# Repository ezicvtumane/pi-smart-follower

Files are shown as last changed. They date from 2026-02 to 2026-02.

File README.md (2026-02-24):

<p align="center">
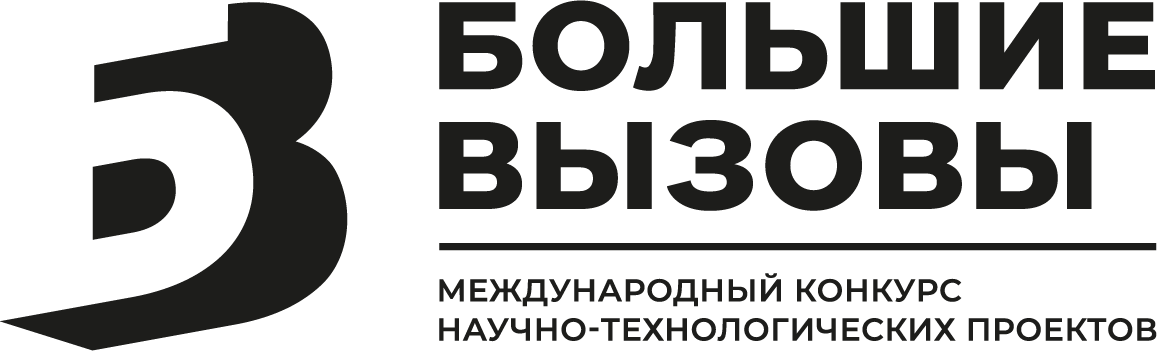
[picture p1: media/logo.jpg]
  
</p>

# Alice's Bot: Autonomous Smart Follower 🤖

Мобильный робот на базе Raspberry Pi 4 с элементами искусственного интеллекта и удаленным веб-управлением. 
Проект разработан в рамках Международного конкурса научно-технологических проектов **«Большие вызовы»** (направления: «Транспортно-логистические системы, морские, авиационные и беспилотные технологии» / «Большие данные, искусственный интеллект, автоматизированные системы и информационная безопасность»).

Робот может управляться вручную через мобильный веб-интерфейс (с трансляцией видео от первого лица), а также умеет автономно ездить за оператором или объектом, ориентируясь по визуальным ArUco-маркерам.

<p align="center">
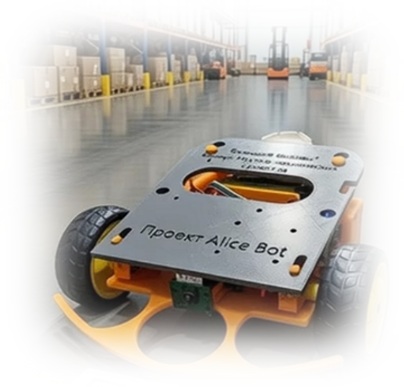
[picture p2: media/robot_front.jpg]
  
</p>

---

## 🧠 Как это работает (Архитектура и Алгоритмы)

Главная фишка программной части (Python 3) в том, что она работает в два независимых потока (через библиотеку `threading`). Один поток постоянно анализирует зрение и рулит моторами, а второй — держит веб-сервер Flask и отдает видео без тормозов.

1. **Компьютерное зрение (OpenCV + Picamera2):** Скрипт захватывает кадр в высоком разрешении для FPV, но для модуля машинного зрения программно ужимает его и переводит в ЧБ. Алгоритм ищет ArUco-маркер (словарь `DICT_4X4_50`) и вычисляет его центр.
2. **Автопилот (П-регулятор):** Если робот видит маркер, программа считает, насколько его центр отклонился от центра камеры. Это отклонение умножается на коэффициент, и разница подается на колеса. В итоге робот плавно подруливает без рывков.
3. **Система безопасности «Автостоп»:** Чтобы робот не врезался в ноги (или в кота), алгоритм непрерывно анализирует ширину маркера. Как только она превышает 180 пикселей (~30 см до объекта), моторы экстренно останавливаются.
4. **Zero-ping интерфейс:** В мобильном браузере обычные клики по кнопкам управления имеют огромную задержку. Я переписала HTML-шаблон Flask, заменив стандартные клики на прямую обработку касаний экрана (`ontouchstart` / `ontouchend`). В итоге отклик стал мгновенным, как на аппаратном джойстике.

---

## 🛠 Железо (Hardware)

* **Мозг:** Одноплатный микрокомпьютер Raspberry Pi 4.
* **Глаза:** Компактный модуль камеры OV5647 (подключен по CSI).
* **Шасси:** Спроектировано мной и напечатано на 3D-принтере (STL-файлы лежат в папке `3d_models`). В качестве пассивного третьего колеса интегрирован гладкий шар от роликового дезодоранта.
* **Драйвер моторов:** Промышленный модуль L298N с радиатором. *(Изначально я использовала компактный L9110S, но он сгорел во время тестов от высоких пусковых токов ТТ-моторов, поэтому схему пришлось переделать под более мощный ключ).*
* **Питание (Два контура):** Сборка 2S Li-ion 18650 (7.4В) питает напрямую драйвер моторов. Для питания чувствительной логики Raspberry Pi используется понижающий импульсный DC-DC преобразователь (выдает стабильные 5В напрямую на пины GPIO 4 и 6).

---

## 🚀 Установка и запуск

1. Склонируйте репозиторий на вашу Raspberry Pi:

```bash
git clone https://github.com/ezicvtumane/pi-smart-follower.git
cd pi-smart-follower
  ```
2. Установите зависимости (камера Picamera2 должна быть включена в настройках ОС):

  ```bash
  pip install -r requirements.txt
  ```
4. Запустите основной скрипт:
  ```bash
  python3 main.py
  ````
5. Откройте интерфейс управления в браузере смартфона или ПК (устройства должны быть в одной Wi-Fi сети):
  ```
  http://<IP_АДРЕС_RASPBERRY>:5000
  ```
---

## ⚙️ Автозагрузка при включении (через systemd)

Чтобы робот был полностью автономным и не требовал подключения по SSH для запуска кода, настроена системная служба `systemd`. Она автоматически поднимает скрипт при включении питания, ожидая подключения Raspberry Pi к Wi-Fi сети (чтобы сервер Flask не упал с ошибкой сети).

1. Создайте файл службы:
```bash
    sudo nano /etc/systemd/system/alicebot.service
```
2. Скопируйте в него содержимое файла `alicebot.service` из этого репозитория.

3. Включите автозагрузку командами:
```bash
    sudo systemctl daemon-reload
    sudo systemctl enable alicebot.service
    sudo systemctl start alicebot.service
```
---

## 🔮 Перспективы развития (Roadmap)

В будущем планируется масштабный апгрейд робота, который переведет его из класса прототипов в полноценную платформу:
* **Внедрение нейросетей:** Переход на Raspberry Pi 5 + AI Kit. Использование легковесных сверточных нейросетей (например, YOLOv8) для детекции людей и управления жестами без бумажных маркеров.
* **Интеграция в Умный дом (IoT):** Подключение робота к серверу Home Assistant по протоколу MQTT для создания «роевого интеллекта» (swarm robotics) и диспетчеризации.
* **Безопасность и автономность:** Установка модуля BMS для аккумуляторов и ультразвуковых сонаров для полностью безопасного перемещения и автовозврата на зарядную станцию.

---

## 🎥 Демонстрация работы

Видео полевых испытаний алгоритмов (езда за меткой, автостоп, интерфейс):
* 📹 [Тест мобильного управления, следования за меткой и автостопа](https://disk.yandex.ru/i/8JQ_mCUT42CxUg)
* 📹 [Тест следования по ArUco маркеру](https://disk.yandex.ru/i/dgs2dP-XnfjGSw)
* 📹 [Тест FPV и следование за котом Серго](https://disk.yandex.ru/i/KrElrjvzCOmklQ)

---
**📝 Автор:** Ковалева Алиса, ученица 9-го класса ГБОУ СОШ №282 г. Санкт-Петербурга (2026 г.). Проект выполнен в рамках инженерно-исследовательской работы.

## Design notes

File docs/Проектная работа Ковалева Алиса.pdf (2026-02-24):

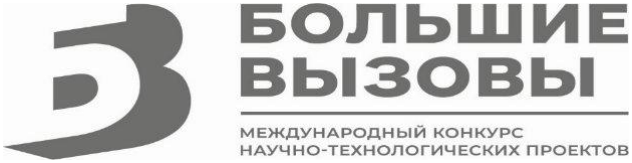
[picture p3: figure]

Направление: «Транспортно-логистические системы, морские, авиационные и беспилотные технологии», «Большие данные, искусственный интеллект, автоматизированные системы и информационная безопасность»

ПРОЕКТНАЯ РАБОТА

Тема: «Разработка мобильного робота с элементами искусственного интеллекта и

удаленным веб-управлением»

Выполнила: ученица 9 «А» класса

ГБОУ СОШ №282 г. Санкт-Петербурга

Ковалева Алиса Ивановна

Санкт-Петербург

2026 г.

### 1. ВВЕДЕНИЕ

Актуальность проекта Развитие современной робототехники неразрывно связано

с компьютерным зрением. Большинство существующих роботизированных платформ

перемещаются «вслепую», опираясь на таймеры или базовые датчики расстояния

(ультразвуковые или лидары). В отличие от них, системы визуальной навигации

позволяют роботу не просто избегать механических столкновений, но и узнавать объекты

в пространстве, анализировать их положение и самостоятельно принимать решения о

корректировке маршрута.

Проблематика Одной из главных проблем современной складской логистики и

автоматизации закрытых помещений (например, больниц или "чистых" зон) является

недоступность спутникового сигнала GPS. Для ориентации тяжелых транспортных

платформ внутри зданий нередко применяются дорогостоящие лазерные дальномеры

(лидары). Использование дешевых оптических камер в связке с бумажными ArUco-

маркерами решает эту проблему, позволяя создать экономичную и высокоточную систему

навигации.

Цель проекта Самостоятельно создание автономного мобильного робота, из

имеющихся в продаже недорогих компонентов, способного не только управляться

дистанционно через веб-интерфейс, но и самостоятельно следовать за целью по заданным

визуальным меткам.

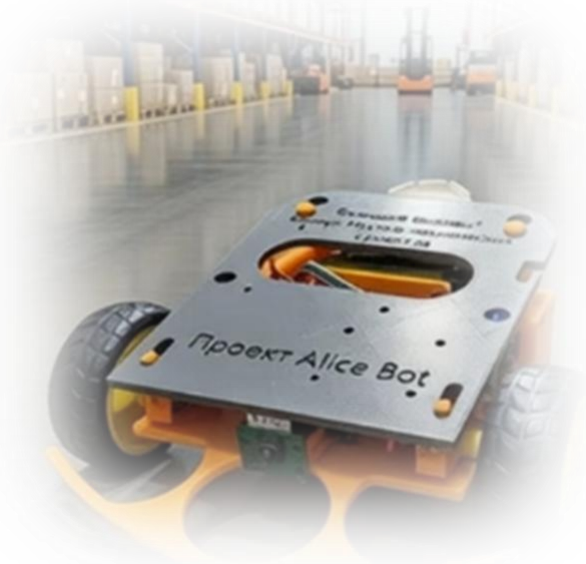
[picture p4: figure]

Задачи проекта:

1. Спроектировать и собрать работающий аппаратный прототип устройства

(разработка шасси, подбор компонентов, реализация подсистемы питания).

2. Реализовать алгоритмы компьютерного зрения для распознавания ArUco-

маркеров и настроить захват видеопотока в операционной системе Linux.

3. Разработать и развернуть кроссплатформенный веб-интерфейс для

обеспечения удобной системы удаленного контроля и FPV-управления.

Объект исследования: Автономные мобильные роботизированные платформы и

система компьютерного зрения.

Предмет исследования: Алгоритмы визуальной навигации (компьютерного

зрения) и системы дистанционного управления на базе веб-технологий.

Практическая значимость: Реализованный в проекте программный код и

аппаратная архитектура являются готовой масштабируемой базой (прототипом) для

создания парка умных тележек, автономно перевозящих грузы и способных безопасно

функционировать рядом с людьми.

ГЛАВА 1. АППАРАТНАЯ РЕАЛИЗАЦИЯ (КОНСТРУКЦИЯ И

ЭЛЕКТРОНИКА)

### 1.1. Выбор вычислительной платформы и базовых компонентов Для

обеспечения достаточной вычислительной мощности, необходимой для обработки

видеопотока в реальном времени, в качестве «мозга» робота мною был выбран

имеющийся у меня в наличии

одноплатный микрокомпьютер

Raspberry Pi 4. В качестве

органа «зрения» я

дополнительно приобрела

недорогой компактный модуль

камеры OV5647,

подключенный напрямую к

интерфейсу CSI

микрокомпьютера. Приводом

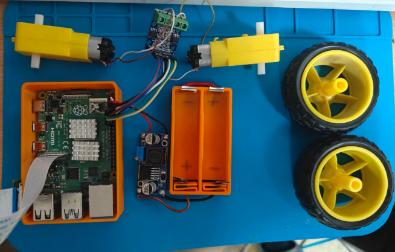
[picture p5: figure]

послужили два мотор-редуктора постоянного тока (ТТ-моторы) с пластиковыми колесами,

обеспечивающие схему управления за счет разности скоростей вращения левого и правого

колес.

### 1.2. Проектирование шасси и 3D-печать (Конструктивная часть)

На начальном этапе прототип робота был

смонтирован на временном шасси при

помощи термоклея для проверки

принципиальной работоспособности

электронных схем. После успешных тестов

я приступила к проектированию

полноценного корпуса. Основные

элементы корпуса и крепления я

изготовила с применением аддитивных

технологий (3D-печать). Это позволило

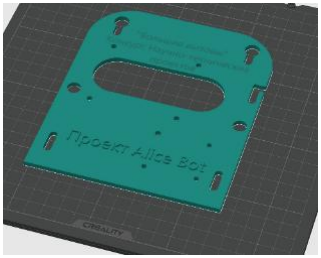
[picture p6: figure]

мне спроектировать точные посадочные места под все компоненты: Raspberry Pi,

держатель для аккумуляторов и моторы.

Особенности компоновки:

- Снижение центра тяжести: Тяжелые элементы (аккумуляторы и мотор-

редукторы) я расположила максимально низко, что исключает опрокидывание платформы

при резких стартах и торможениях.

- Экологичный подход к деталям: В дифференциальном приводе роботу

требуется третья, пассивная точка опоры. Вместо покупки готового поворотного колеса,

создающего люфты, мною был применен творческий подход: в корпус был интегрирован

гладкий шар от использованного роликового дезодоранта. Это обеспечило роботу

скольжение по любым поверхностям.

- Специально для конкурса «Большие вызовы» мною была спроектирована и

распечатана кастомная верхняя крышка с названием проекта.

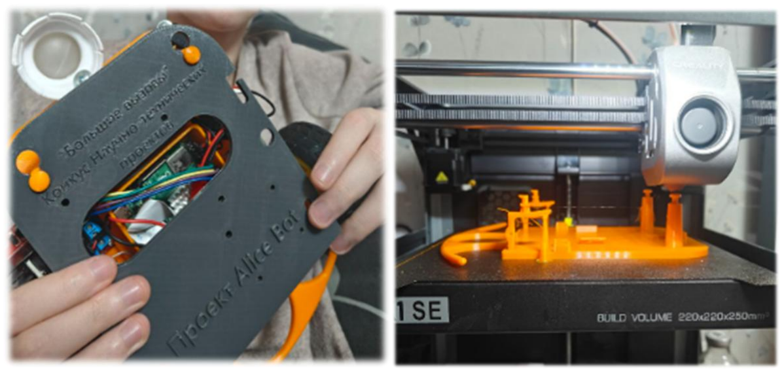
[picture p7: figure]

### 1.3. Разработка подсистемы питания Главная сложность аппаратной части

заключалась в высоких требованиях Raspberry Pi к стабильности тока. При пиковых

нагрузках на процессор (во время обработки видео, старте двигателей) обычные

пауэрбанки давали просадку напряжения, что приводило к перезагрузке системы. Для

решения проблемы была спроектирована раздельная система питания на базе двух

высокотоковых Li-ion аккумуляторов формата 18650 со встроенной защитой

(конфигурация 2S, номинальное напряжение 7.4В). Было принято решение разделить

питание на два контура:

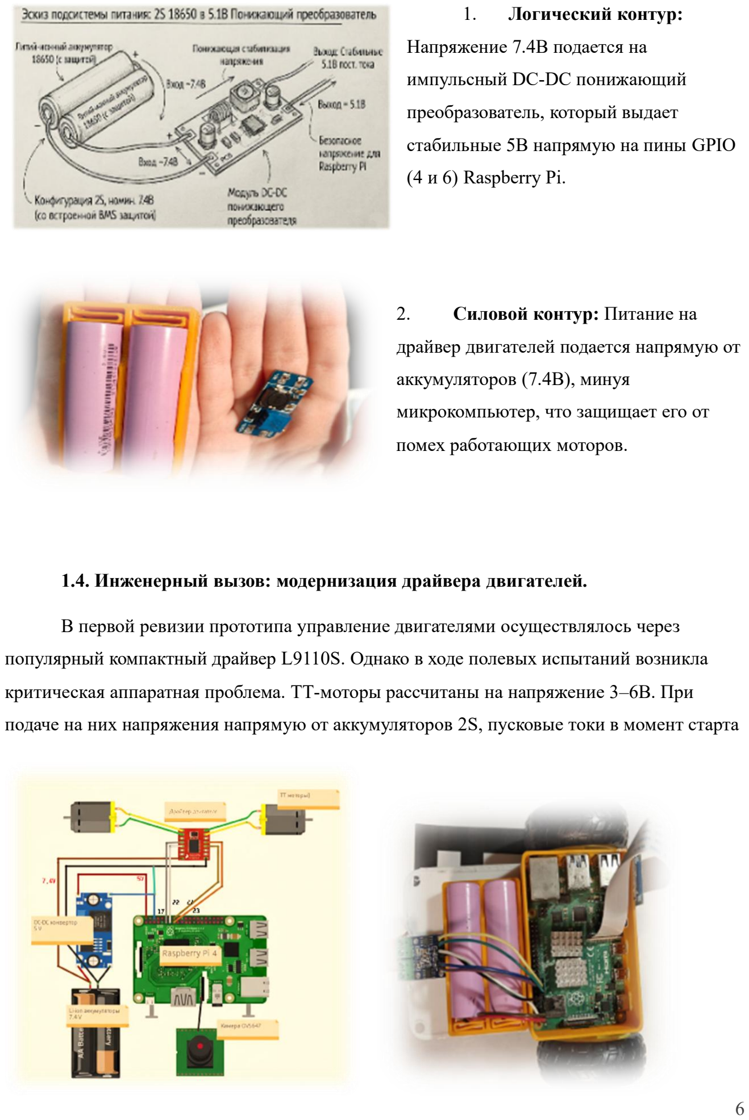
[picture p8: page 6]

1. Логический контур:

Напряжение 7.4В подается на

импульсный DC-DC понижающий

преобразователь, который выдает

стабильные 5В напрямую на пины GPIO

(4 и 6) Raspberry Pi.

2. Силовой контур: Питание на

драйвер двигателей подается напрямую от

аккумуляторов (7.4В), минуя

микрокомпьютер, что защищает его от

помех работающих моторов.

1.4. Инженерный вызов: модернизация драйвера двигателей.

В первой ревизии прототипа управление двигателями осуществлялось через

популярный компактный драйвер L9110S. Однако в ходе полевых испытаний возникла

критическая аппаратная проблема. ТТ-моторы рассчитаны на напряжение 3–6В. При

подаче на них напряжения напрямую от аккумуляторов 2S, пусковые токи в момент старта или при встрече с препятствием резко возрастали до. Лимит чипа L9110S составляет всего

800 мА, из-за чего во время одного из тестов базовый драйвер сгорел от перегрева.

Проблема была успешно локализована и решена путем замены силового ключа на

имеющийся у меня в наличии более мощный но прожорливый промышленный модуль

L298N. Этот драйвер оснащен массивным радиатором охлаждения и способен

выдерживать пиковые токи до 3А на канал, что сделало работу шасси абсолютно

безотказной даже при повышенном напряжении, но ценою этого стало большее

потребление тока. Управление модулем L298N осуществляется через ШИМ-сигналы с

пинов GPIO 17, 27, 22 и 23.

### 1.5. Экономическая эффективность выбранной архитектуры

Традиционные промышленные AGV-платформы, используемые на складах,

опираются на системы лазерного сканирования пространства (лидары). Стоимость

простейшего 2D-лидара начинается составляет десятки тысяч рублей, что многократно

увеличивает итоговую стоимость каждого робота в парке. Предложенная в моем проекте

архитектура визуальной навигации опирается на связку дешевой оптической камеры

(купленной нами буквально за 500 рублей) и распечатанных на принтере бумажных

ArUco-маркеров, себестоимость которых в сравнении с лидаром стремится к нулю.

Использование алгоритмов компьютерного зрения позволяет достичь точности

позиционирования, сопоставимой с лазерными радарами, при этом снижая стоимость

аппаратной базы робота в несколько раз. Это делает технологию экономически

привлекательной для масштабирования на предприятиях малого и среднего бизнеса.

ГЛАВА 2. ПРОГРАММНАЯ РЕАЛИЗАЦИЯ И КОМПЬЮТЕРНОЕ ЗРЕНИЕ

### 2.1. Выбор программного стека и

архитектуры Проект написан на

высокоуровневом языке программирования

Python 3 и функционирует под

управлением операционной системы

Raspberry Pi OS (на базе ядра Linux). Для

прямого взаимодействия с аппаратной

частью (управления мотор-редукторами)

мною применена библиотека GPIOZero, а

для захвата видеокадров с аппаратного

интерфейса камеры — современная

библиотека Picamera2 (старая библиотека

в новой ОС отказалась работать).

Обработка визуальных данных

реализована с помощью открытой

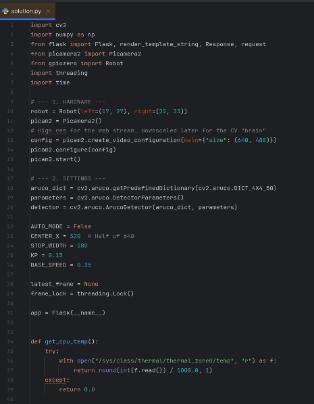
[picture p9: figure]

библиотеки компьютерного зрения OpenCV, а математические расчеты векторов движения

и расстояний выполняются средствами библиотеки NumPy.

### 2.2. Система визуальной навигации (ArUco-маркеры)

В отличие от простых

роботизированных систем, которые

перемещаются «вслепую» по

запрограммированным таймерам, мой

бот использует полноценную систему

технического зрения (Computer Vision).

Основой навигации стала технология

распознавания пространственных ArUco-

маркеров. В проекте мною задействован

стандартный словарь маркеров

«DICT_4X4_50». Я выбрала данную

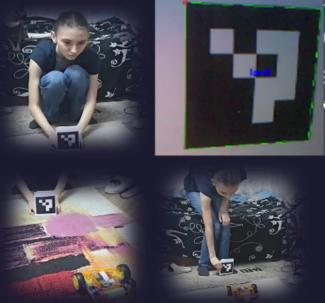
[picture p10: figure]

технологию из-за ее достаточно высокой устойчивости к визуальному шуму и изменениям освещенности. Отладка программы, корректировка коэффициентов и визуальный контроль

по камере осуществлялись через VNC-сервер, установленный в ОС робота посредством

ПК.

### 2.3. Конвейер обработки визуальных данных Обработка видеопотока на

мобильном микрокомпьютере требует жесткой оптимизации для сохранения высокой

частоты кадров (FPS). Исходный видеокадр с камеры захватывается в высоком разрешении

для качественной трансляции оператору по сети. Однако для модуля машинного зрения

этот кадр программно ужимается в разрешении и переводится в градации серого

(Grayscale). Алгоритм OpenCV производит бинаризацию изображения (превращая пиксели

в строго черные и белые), после чего ищет замкнутые контуры. Если найденный контур

представляет собой четырехугольник, программа извлекает его внутренний паттерн и

сверяет с матрицей словаря DICT_4X4_50. Если паттерн совпадает с искомым ID, функция

возвращает координаты четырех углов маркера, на основе которых высчитывается его

центральная точка. Весь этот процесс выполняется десятки раз в секунду.

### 2.4. Алгоритм следования и П-регулятор Логика автономного следования

построена на непрерывном математическом вычислении координат центра ArUco-маркера

в кадре. Для корректировки траектории движения платформы внедрен Пропорциональный

регулятор. Принцип его работы заключается в следующем: чем сильнее целевой маркер

смещается (отклоняется) от центра поля зрения камеры, тем большая разность скоростей

подается на левое и правое колесо. Это заставляет привод робота плавно подруливать к

цели без резких рывков.

### 2.5. Система безопасности «Автостоп»

Для предотвращения физических столкновений робота с

объектами или оператором я реализовала программную

функцию "Автостоп". В процессе движения алгоритм

непрерывно анализирует ширину захваченного маркера в

пикселях. Экспериментальным путем было установлено

пороговое значение: если ширина маркера превышает

180 единиц, это означает, что объект находится слишком

близко. Примерное расстояние автоматической остановки

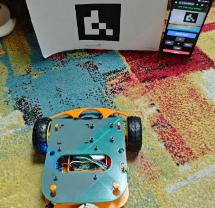
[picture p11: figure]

при этом составило около 30 см. В этот момент колеса мгновенно останавливаются, и

выполнение программы переходит в безопасный режим ожидания. Если снова отдалить

метку от камеры, робот автоматически возобновляет следование за ней.

ГЛАВА 3. ВЕБ-ИНТЕРФЕЙС И СИСТЕМА УДАЛЕННОГО УПРАВЛЕНИЯ

3.1. Разработка кроссплатформенного сервера.

Для обеспечения удобства взаимодействия с пользователем, помимо автономного

режима, было разработано легковесное веб-приложение для перевода бота в режим

прямого FPV-контроля. Серверная часть реализована на базе фреймворка Flask. При

запуске скрипта Raspberry Pi поднимает локальный веб-сервер, который транслирует

видеопоток в формате MJPEG и принимает входящие HTTP-запросы от смартфона или

компьютера пользователя. Данное решение обеспечивает полную всеядность и

автономность системы без необходимости устанавливать дополнительное ПО. В режиме

прямого контроля управление роботом осуществляется прямо через браузер.

### 3.2. Пользовательский интерфейс и телеметрия

На панель управления в реальном времени выводится

видеопоток с камеры, что позволяет оператору

управлять роботом вне зоны прямой видимости.

Дополнительно на экран выводятся важные показатели

телеметрии, такие как текущий режим работы

(Ручной/Авто) и температура CPU микрокомпьютера.

Взаимодействие клиента и сервера настроено

асинхронно: отправка команд на двигатели и

переключение режимов происходят в фоновом режиме

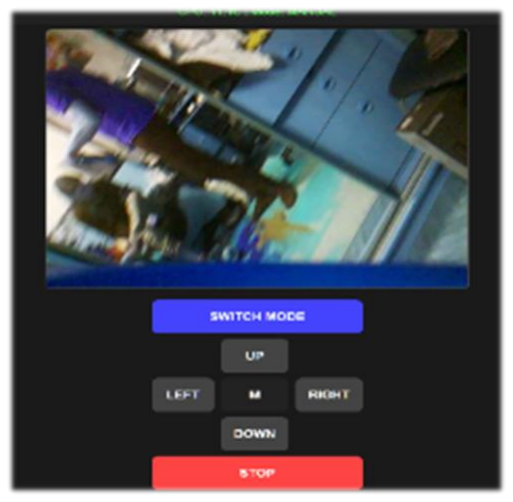
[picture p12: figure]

через Fetch API, что исключает необходимость перезагрузки веб-страницы.

### 3.3. Сенсорная оптимизация (Устранение задержек)

При работе с ПК проблем не возникло, но в браузере

смартфона обработка нажатий приводился к сбоям.

Поэтому критически важной задачей при создании

пульта управления на базе браузера было устранение

задержек (пинга) при нажатии кнопок направления.

При создании интерфейса стандартные программные

клики мыши я заменила на прямую обработку касаний

экрана (Touch Events). Эта оптимизация позволила

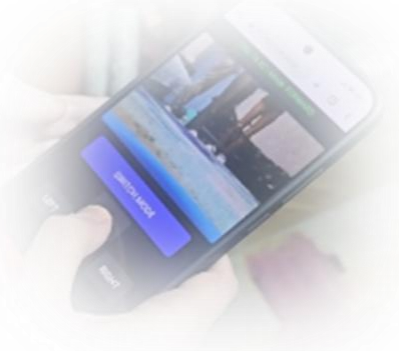
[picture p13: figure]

добиться мгновенного отклика мобильного интерфейса, сопоставимого с аппаратными

джойстиками и нормализации работы с мобильными дисплеями.

ЗАКЛЮЧЕНИЕ (ВЫВОДЫ И РЕЗУЛЬТАТЫ)

Проект по созданию мобильного робота с

элементами искусственного интеллекта был

сопряжен с рядом сложностей, но успешно

прошел все этапы полевых испытаний. В

ходе работы был создан полностью

функционирующий прототип, который

доказал эффективность выбранных

инженерных и программных решений.

Главная цель работы достигнута: робот

способен не только управляться

дистанционно, но и самостоятельно

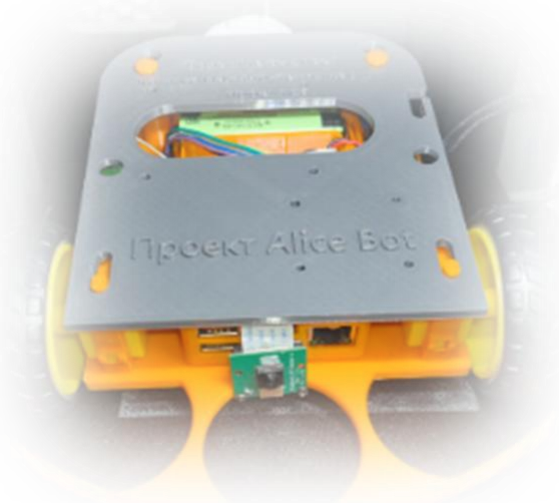
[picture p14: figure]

следовать за оператором по визуальным меткам (была даже реализована программа

следования за Felis catus, путем прикрепления к нему ArUco-маркера). Разработанный

кроссплатформенный веб-интерфейс обеспечил надежную систему удаленного

управления с минимальными задержками как на ПК, так и на экране мобильного

телефона.

Стратегии применения и масштабируемость

Созданный робот — это не просто

игрушечная радиоуправляемая модель, это

готовый программно-аппаратный прототип

автономной транспортной платформы для

закрытых помещений. Использование

компьютерного зрения и системы ArUco-

маркеров успешно решает фундаментальную

проблему отсутствия или нестабильности

спутникового сигнала GPS на крупных

складах маркетплейсов и в промышленных

цехах.

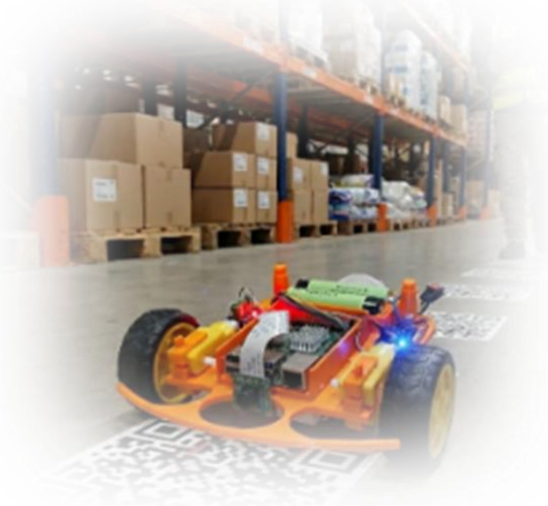
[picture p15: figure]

Данная технология визуальной навигации позволяет роботу ориентироваться в

пространстве с высокой точностью и безопасно взаимодействовать с объектами без

применения дорогостоящих лазерных дальномеров. Это значительно снижает себестоимость каждого отдельного устройства по сравнению с промышленными

аналогами, делая возможным массовое развертывание парков умных тележек даже на

предприятиях малого и среднего бизнеса.

Помимо складской логистики, гибкость программного кода и

кроссплатформенность веб-интерфейса по моему мнению, открывают следующие сферы

применения технологии:

- Медицина и социальная сфера: Создание роботов-ассистентов для работы в

стерильных зонах больниц и инфекционных отделениях. Робот может

автоматически следовать за врачом, перевозя тяжелое диагностическое

оборудование или медикаменты, а также использоваться как "умная" тележка для

бесконтактной доставки еды пациентам, минимизируя риск заражения персонала.

- Умный дом и автоматизация зданий: Прототип может стать основой для

создания персональных домашних помощников. Благодаря возможности работы в

локальной сети, такие роботы способны интегрироваться с системами умного дома,

осуществлять видеопатрулирование помещений, переносить предметы или

работать в связке с другими IoT-устройствами внутри единой экосистемы здания.

- Беспилотная авиация (БПЛА): Использование визуальных маркеров,

расположенных на корпусе наземного бота, для высокоточной автоматической

посадки дронов на заданные, в том числе движущиеся, платформы. Это критически

важно для создания мобильных зарядных станций и полностью автономных систем

курьерской доставки.

- Промышленность и интралогистика: Синхронизация работы роботизированных

платформ на заводских конвейерах со сборкой деталей. Автоматизированный

подвоз тяжелых комплектующих от склада к рабочим станциям строго по

расписанию или по вызову сотрудника (через захват персональной метки-

идентификатора).

- Сельское хозяйство (тепличные комплексы): Навигация в крупных крытых

агропромышленных комплексах, где сигнал GPS глушится металлическими

конструкциями. Роботы могут следовать за сборщиками урожая, принимая на себя

вес собранных овощей, или автономно вывозить ящики с готовой продукцией к

зоне отгрузки.

- Мониторинг и диспетчеризация: Встроенная система удаленного управления

посредством веб-приложения позволяет не только осуществлять прямой FPV-

контроль, но и в перспективе организовать единый диспетчерский центр. Это даст

возможность отслеживать перемещения всего парка роботов в реальном времени,

анализировать их телеметрию и оптимизировать маршруты на предприятиях

Перспективы развития (Модернизация)

В будущем планируется внедрить ряд аппаратных и программных улучшений для

повышения автономности и надежности системы:

1. Оптимизация питания: Замена текущего драйвера моторов на более

современный и экономичный модуль DRV8833. Данная замена позволяет уменьшить вес и

энергопотребление робота.

2. Контроль батарей: Интеграция полноценной платы BMS (Battery

Management System) и датчиков уровня заряда для безопасной эксплуатации Li-ion

аккумуляторов и реализации функции автоматического возврата на зарядную станцию.

3. Резервная безопасность: Добавление ультразвуковых датчиков (сонаров) в

качестве дублирующей системы для предотвращения физических столкновений с

объектами, на которых нет визуальных маркеров.

4. Внедрение нейросетей: В будущем я планирую заменить Raspberry Pi 4 на

более мощную пятую версию или аналог с ИИ-ускорителем. Это позволит роботу

отказаться от бумажных меток и использовать настоящие нейросети (например, YOLO).

Он сможет распознавать силуэты людей, уверенно объезжать любые препятствия и даже

понимать жестовые команды в реальном времени.

5. Интеграция в умный дом (IoT): Я хочу связать робота с системами

автоматизации зданий по протоколу MQTT. Поскольку у меня уже есть опыт настройки

серверов Home Assistant (моя Raspberry Pi ранее являлась сервером подобного умного

дома), я планирую сделать робота полноценным узлом такой сети. В перспективе это

позволит объединить несколько подобных тележек в единый «рой», где они будут сами

обмениваться данными, координировать маршруты и распределять задачи без участия

человека

ГЛОССАРИЙ (ТЕРМИНЫ И СОКРАЩЕНИЯ)

AGV (Automated Guided Vehicle) — автоматизированная транспортная тележка, перемещающаяся по заданному маршруту без участия человека (применяется в складской логистике).

ArUco-маркер — синтетическая квадратная метка с уникальным контрастным паттерном, используемая в компьютерном зрении для определения координат и ориентации объектов в пространстве.

BMS (Battery Management System) — электронная плата управления батареей, защищающая литий-ионные аккумуляторы от переразряда, перезаряда и короткого замыкания.

Computer Vision (Компьютерное зрение) — область искусственного интеллекта, связанная с анализом изображений и видео.

CSI (Camera Serial Interface) — высокоскоростной аппаратный интерфейс для прямого подключения модулей камер к микрокомпьютерам.

DC-DC преобразователь — электронное устройство, преобразующее постоянное напряжение одной величины в постоянное напряжение другой (в данном проекте — понижающее напряжение с 7.4В до стабильных 5В).

Flask — легковесный веб-фреймворк для языка Python, предназначенный для создания веб-приложений и локальных серверов.

FPV (First Person View) — вид от первого лица; трансляция видео с камеры робота на экран оператора в реальном времени.

GPIO (General-Purpose Input/Output) — интерфейс ввода-вывода общего назначения, позволяющий микрокомпьютеру управлять внешними электронными компонентами (моторами, датчиками, реле).

IoT (Internet of Things / Интернет вещей) — концепция вычислительной сети физических предметов («вещей»), оснащенных встроенными датчиками и ПО для взаимодействия друг с другом или с внешней средой без участия человека

MQTT (Message Queuing Telemetry Transport) — легковесный сетевой протокол обмена сообщениями, специально созданный для телеметрии и межмашинного взаимодействия (M2M) в системах интернета вещей в условиях нестабильных каналов связи.

OpenCV (Open Source Computer Vision Library) — библиотека алгоритмов компьютерного зрения, обработки изображений и численных алгоритмов с открытым исходным кодом.

Raspberry Pi — одноплатный микрокомпьютер, обладающий процессором и оперативной памятью, работающий под управлением полноценной операционной системы семейства Linux.

YOLO (You Only Look Once) — архитектура высокоскоростных сверточных нейронных сетей, предназначенная для детекции, распознавания и классификации множества объектов на видео в режиме реального времени.

Лидар (LiDAR) — технология измерения расстояний путем излучения лазерных импульсов; используется для сканирования окружающего пространства.

П-регулятор (Пропорциональный регулятор) — алгоритм управления, формирующий управляющий сигнал, прямо пропорциональный отклонению текущей величины от целевой (в проекте используется для плавного подруливания робота).

ШИМ (Широтно-импульсная модуляция) — процесс управления мощностью, подводимой к электромотору, путем изменения скважности импульсов, что позволяет плавно регулировать скорость вращения колес.

Ссылки на видео демонстрацию:

https://disk.yandex.ru/i/8JQ_mCUT42CxUg

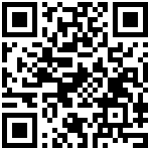
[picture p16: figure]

https://disk.yandex.ru/i/dgs2dP-XnfjGSw

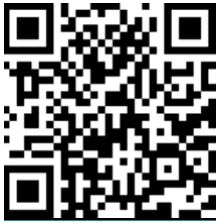
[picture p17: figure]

https://disk.yandex.ru/i/KrElrjvzCOmklQ

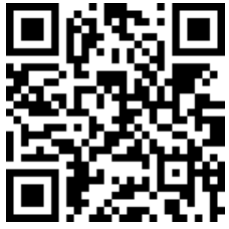
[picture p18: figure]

Весь исходный код проекта, чертежи деталей и видео демонстрация работы

алгоритмов опубликованы в открытом доступе в репозитории.

https://github.com/ezicvtumane/pi-smart-follower.git

СПИСОК ИСПОЛЬЗОВАННОЙ ЛИТЕРАТУРЫ И ИНТЕРНЕТ-РЕСУРСОВ

1. Юревич, Е. И. Основы робототехники: учебное пособие / Е. И. Юревич. —

4-е изд., перераб. и доп. — Санкт-Петербург: БХВ-Петербург, 2020. — 304 с.

[Электронный ресурс]. – Режим доступа: https://elib.spbstu.ru/dl/325.pdf/download/325.pdf

2. Siegwart R., Nourbakhsh I. R., Scaramuzza D. Introduction to Autonomous

Mobile Robots. — 2nd ed. — Cambridge: MIT Press, 2011. — 472 p.

3. Основы навигации в пространстве: методическое пособие / ГК Геоскан.

[Электронный ресурс]. – Режим доступа: https://disk.yandex.ru/i/HxiQNz8YN4EqgQ

4. Официальная документация Raspberry Pi (Raspberry Pi OS, GPIO)

[Электронный ресурс]. – Режим доступа: https://www.raspberrypi.com/documentation/

5. Документация библиотеки компьютерного зрения OpenCV (Open Source

Computer Vision Library) [Электронный ресурс]. – Режим доступа: https://docs.opencv.org/ (https://www.google.com/search?q=https://docs.opencv.org/)

6. Документация микрофреймворка Flask (Python) [Электронный ресурс]. –

Режим доступа: https://flask.palletsprojects.com/

7. Основы работы с модулем камеры Picamera2 [Электронный ресурс]. – Режим

доступа: https://picamera.readthedocs.io/

8. Ковалева А. И. Исходный код, видео работы и документация проекта «Alice's

Bot» (Репозиторий GitHub) [Электронный ресурс]. – Режим доступа:

https://github.com/ezicvtumane/pi-smart-follower.git

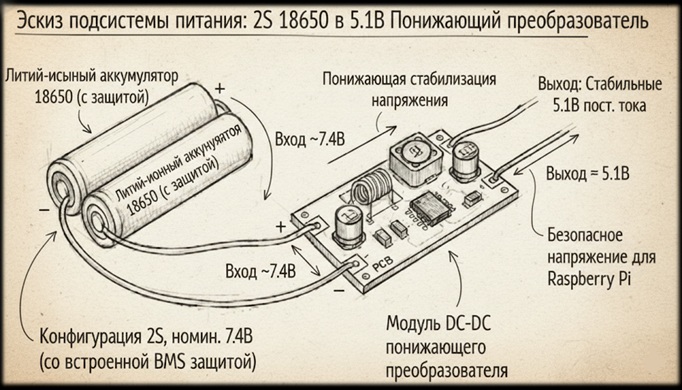
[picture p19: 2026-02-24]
hardware/Подсистема питания.jpg

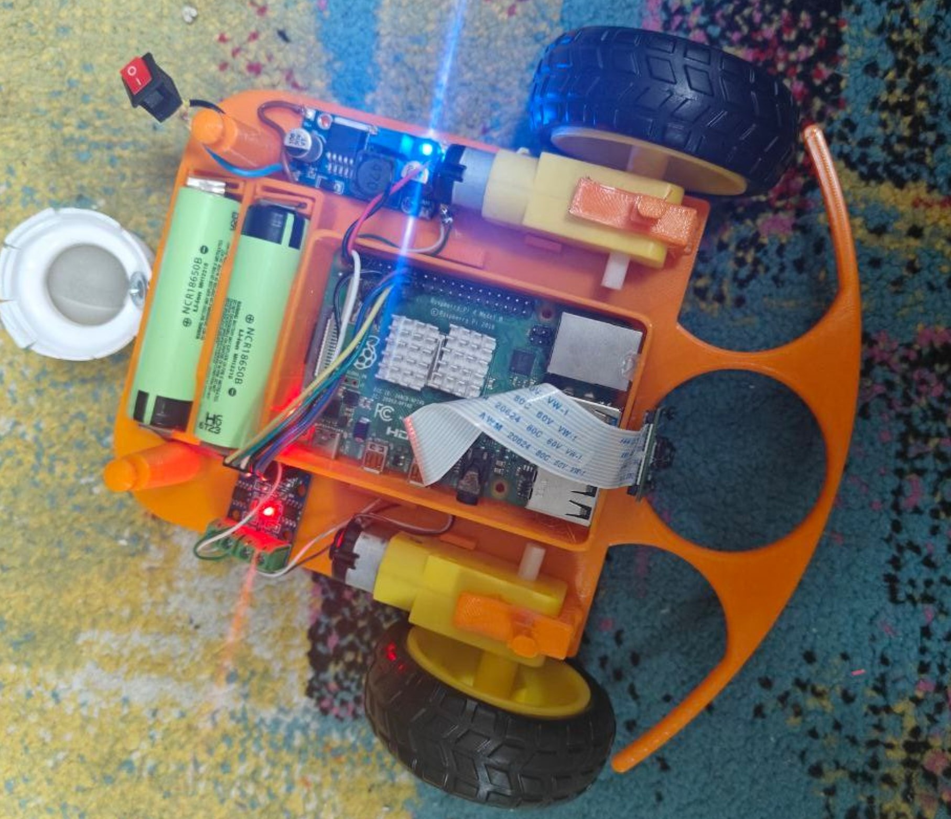
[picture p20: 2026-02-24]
hardware/схема продключения проводов.jpg

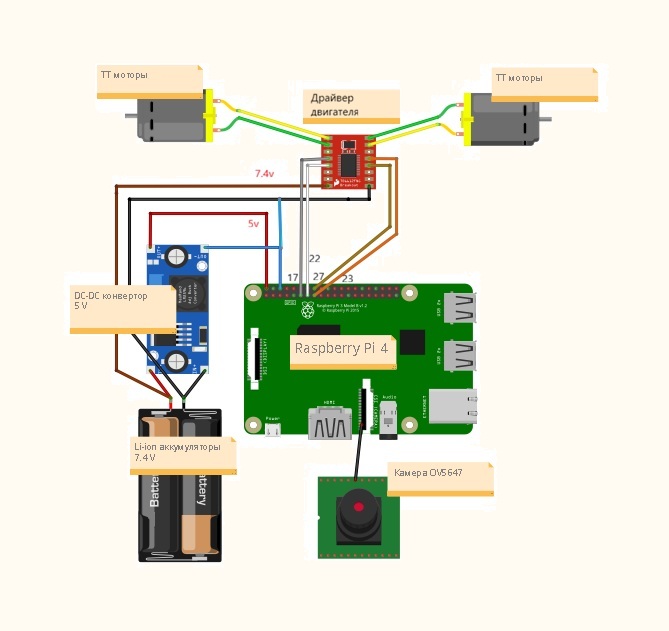
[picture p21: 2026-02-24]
hardware/power_schematic.jpg

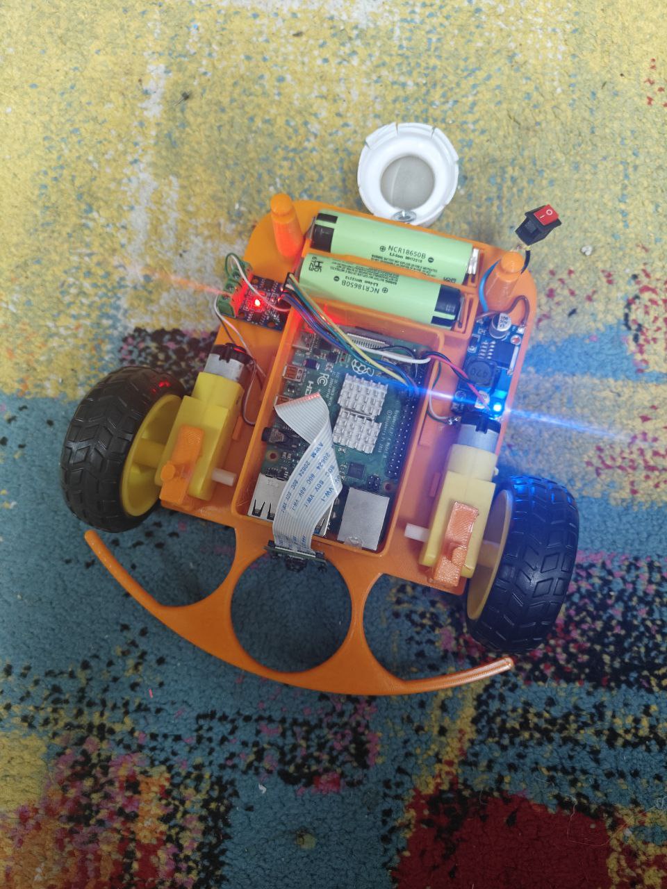
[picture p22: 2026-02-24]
media/Компоновка робота.jpg

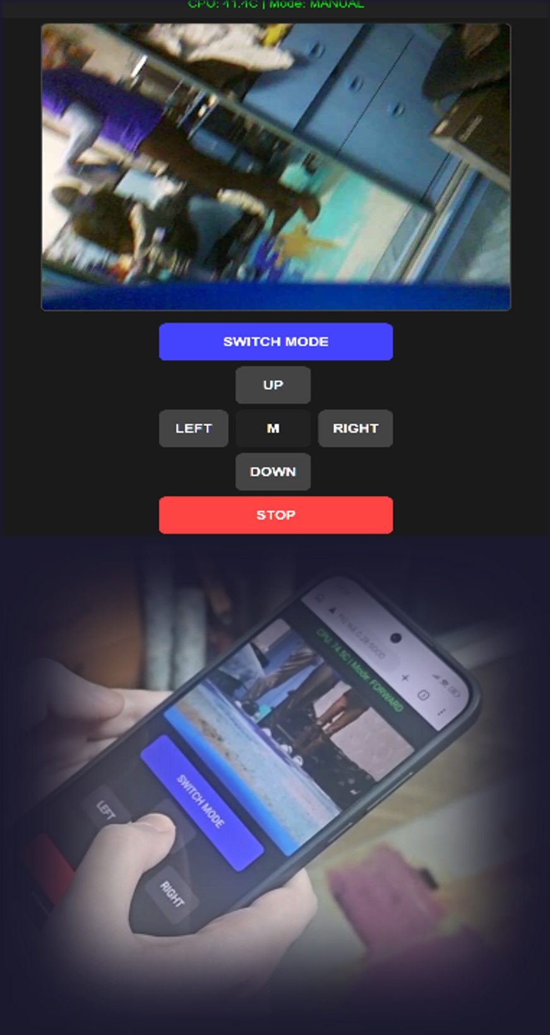
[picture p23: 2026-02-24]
media/Интерфейс.jpg

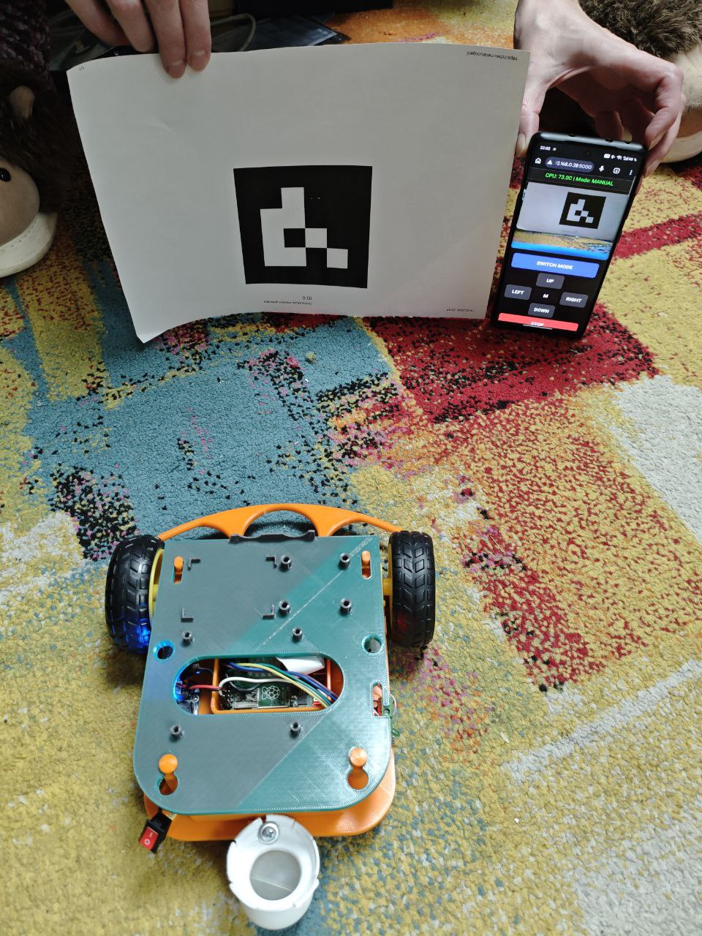
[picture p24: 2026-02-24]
media/Робот с меткой.jpg

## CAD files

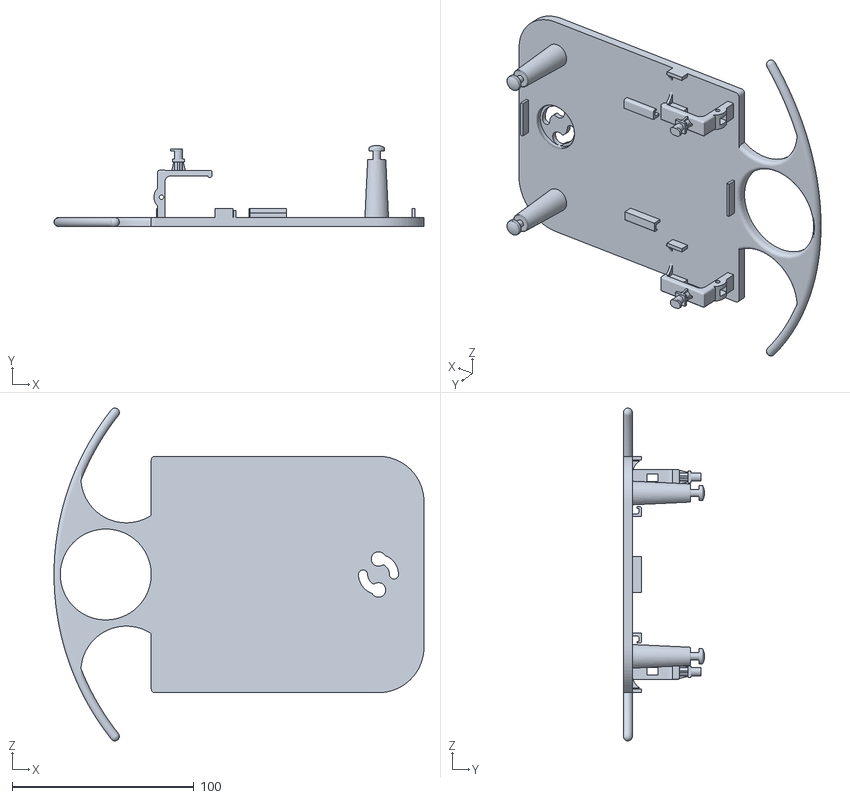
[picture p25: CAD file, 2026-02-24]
3d_models/Robot_base.stl
203.5 x 44.7 x 183.0

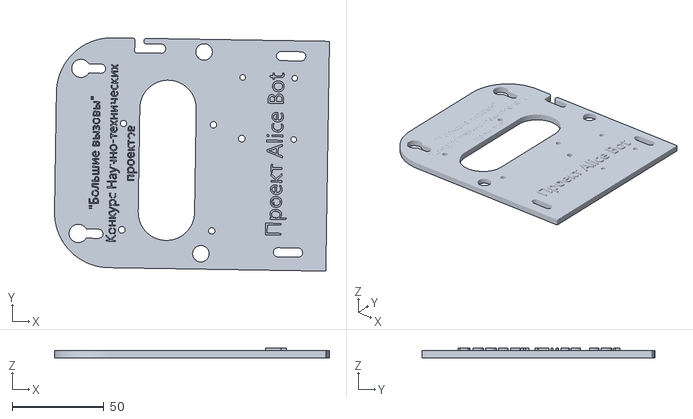
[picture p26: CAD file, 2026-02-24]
3d_models/Robot_cover.stl
149.9 x 127.2 x 5.22

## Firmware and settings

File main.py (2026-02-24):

import cv2
import numpy as np
from flask import Flask, render_template_string, Response, request
from picamera2 import Picamera2
from gpiozero import Robot
import threading
import time

# Подключаем моторы.
# левый мотор висит на пинах 17 и 27, правый - на 22 и 23.
robot = Robot(left=(17, 27), right=(22, 23))

# Запускаем  камеру 
picam2 = Picamera2()
config = picam2.create_video_configuration(main={"size": (640, 480)})
picam2.configure(config)
picam2.start()

# Настройки для поиска меток
aruco_dict = cv2.aruco.getPredefinedDictionary(cv2.aruco.DICT_4X4_50)
parameters = cv2.aruco.DetectorParameters()
detector = cv2.aruco.ArucoDetector(aruco_dict, parameters)

# Мои настройки и константы
AUTO_MODE = False  # Со старта робот стоит в ручном режиме
CENTER_X = 320  # Центр экрана (половина от 640)
STOP_WIDTH = 180  # Экспериментально: если ширина метки > 180px, это ~30 см, надо тормозить
KP = 0.01  # Коэффициент для плавного подруливания (П-регулятор)
BASE_SPEED = 0.55  # Базовая скорость моторов

latest_frame = None  # Сюда кадры для веба
frame_lock = threading.Lock()

app = Flask(__name__)


def autonomous_loop():
    """Этот поток отвечает за зрение и езду за меткой"""
    global AUTO_MODE, latest_frame

    while True:
        frame = picam2.capture_array()

        # Переводим в ЧБ, чтобы OpenCV считал быстрее
        gray = cv2.cvtColor(frame, cv2.COLOR_BGR2GRAY)
        corners, ids, rejected = detector.detectMarkers(gray)

        if ids is not None and AUTO_MODE:
            # Рисуем зеленую рамку вокруг метки для красоты в FPV
            cv2.aruco.drawDetectedMarkers(frame, corners, ids)

            c = corners[0][0]
            marker_width = c[1][0] - c[0][0]
            marker_center_x = int((c[0][0] + c[1][0] + c[2][0] + c[3][0]) / 4)

            # Система безопасности
            if marker_width > STOP_WIDTH:
                robot.stop()
            else:
                # Математика П-регулятора
                error = CENTER_X - marker_center_x

                left_speed = BASE_SPEED - (error * KP)
                right_speed = BASE_SPEED + (error * KP)

                # Защита от выхода за пределы (-1.0 ... 1.0)
                left_speed = max(-1.0, min(1.0, left_speed))
                right_speed = max(-1.0, min(1.0, right_speed))

                robot.value = (left_speed, right_speed)

        elif AUTO_MODE:
            # Если метка потерялась - стоим и ждем
            robot.stop()

        # Сохраняем кадр, чтобы сервер Flask мог его забрать
        with frame_lock:
            latest_frame = frame.copy()

        time.sleep(0.05)  # Небольшая пауза, чтобы не перегреть CPU


def generate_mjpeg():
    """Генератор видеопотока для браузера"""
    global latest_frame
    while True:
        with frame_lock:
            if latest_frame is None:
                continue
            ret, jpeg = cv2.imencode('.jpg', latest_frame)
            if not ret:
                continue
            frame_bytes = jpeg.tobytes()

        yield (b'--frame\r\n'
               b'Content-Type: image/jpeg\r\n\r\n' + frame_bytes + b'\r\n')


@app.route('/video_feed')
def video_feed():
    return Response(generate_mjpeg(), mimetype='multipart/x-mixed-replace; boundary=frame')


@app.route('/command', methods=['POST'])
def command():
    """Принимаем команды от кнопок на экране смартфона"""
    global AUTO_MODE
    cmd = request.form.get('cmd')

    if cmd == 'switch_mode':
        AUTO_MODE = not AUTO_MODE
        robot.stop()
        return "Mode switched"

    if not AUTO_MODE:
        if cmd == 'up':
            robot.forward(BASE_SPEED)
        elif cmd == 'down':
            robot.backward(BASE_SPEED)
        elif cmd == 'left':
            robot.left(BASE_SPEED)
        elif cmd == 'right':
            robot.right(BASE_SPEED)
        elif cmd == 'stop':
            robot.stop()

    return "OK"


# HTML интерфейс. используем ontouchstart вместо onclick, 
# чтобы на смартфонах не было задержки (пинга) при нажатии.
HTML_TEMPLATE = """
<!DOCTYPE html>
<html>
<head>
    <meta name="viewport" content="width=device-width, initial-scale=1, maximum-scale=1, user-scalable=no">
    <title>Alice's Bot Control</title>
    <style>
        body { background-color: #222; color: white; text-align: center; font-family: sans-serif; touch-action: manipulation; }
        img { width: 100%; max-width: 640px; border: 2px solid #555; margin-bottom: 15px;}
        .btn { padding: 20px; margin: 5px; font-size: 18px; background-color: #444; color: white; border: none; border-radius: 10px; width: 80px; }
        .btn-wide { width: 200px; background-color: #3b5998; margin-bottom: 10px;}
        .btn-stop { background-color: #cc0000; width: 200px; }
    </style>
</head>
<body>
    <h2>Alice's Bot - FPV Control</h2>
    <img src="/video_feed" />
    <br>
    <button class="btn btn-wide" onclick="sendCommand('switch_mode')">РУЧНОЙ / АВТО</button>
    <br>
    <table>
        <tr>
            <td></td>
            <td><button class="btn" ontouchstart="sendCommand('up')" ontouchend="sendCommand('stop')" onmousedown="sendCommand('up')" onmouseup="sendCommand('stop')">Вперед</button></td>
            <td></td>
        </tr>
        <tr>
            <td><button class="btn" ontouchstart="sendCommand('left')" ontouchend="sendCommand('stop')" onmousedown="sendCommand('left')" onmouseup="sendCommand('stop')">Влево</button></td>
            <td><button class="btn btn-stop" onclick="sendCommand('stop')">СТОП</button></td>
            <td><button class="btn" ontouchstart="sendCommand('right')" ontouchend="sendCommand('stop')" onmousedown="sendCommand('right')" onmouseup="sendCommand('stop')">Вправо</button></td>
        </tr>
        <tr>
            <td></td>
            <td><button class="btn" ontouchstart="sendCommand('down')" ontouchend="sendCommand('stop')" onmousedown="sendCommand('down')" onmouseup="sendCommand('stop')">Назад</button></td>
            <td></td>
        </tr>
    </table>

    <script>
        function sendCommand(cmd) {
            fetch('/command', {
                method: 'POST',
                headers: { 'Content-Type': 'application/x-www-form-urlencoded' },
                body: 'cmd=' + cmd
            });
        }
    </script>
</body>
</html>
"""


@app.route('/')
def index():
    return render_template_string(HTML_TEMPLATE)


if __name__ == '__main__':
    # Запускаем автопилот в фоновом потоке
    auto_thread = threading.Thread(target=autonomous_loop, daemon=True)
    auto_thread.start()

    # Запускаем сервер на порту 5000
    app.run(host='0.0.0.0', port=5000, debug=False, threaded=True)

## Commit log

2026-02-20 Create схема
2026-02-20 Create пояснительная записка
2026-02-24 Rename media/5249050137592534888.jpg to Робот с меткой.jpg
2026-02-24 Create main.py
    ранее super robot.py
2026-02-24 Create Аппаратное обеспечение
